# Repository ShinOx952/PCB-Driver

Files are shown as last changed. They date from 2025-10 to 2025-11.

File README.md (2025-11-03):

# Diseño de Driver de Potencia (Altium Designer) 

**Estado del Proyecto:** Diseño completado. El informe técnico completo está finalizado y disponible en este repositorio.

---

## 1. Vistas del Proyecto (Renders 3D)

**(Imagen 12: Vista Superior 3D)** 
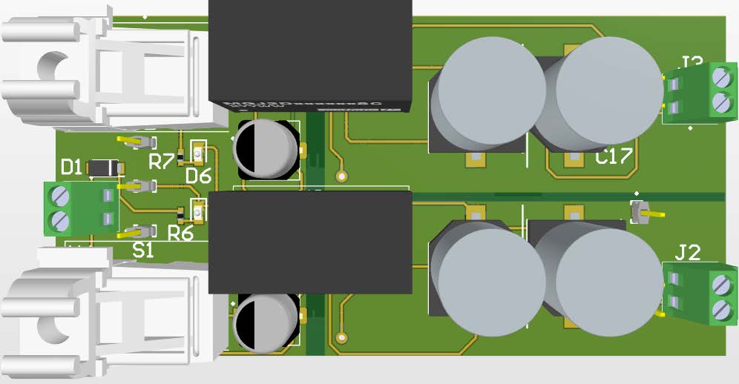
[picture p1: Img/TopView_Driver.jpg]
Vista Superior del PCB


**(Imagen 13: Vista Inferior 3D)** 
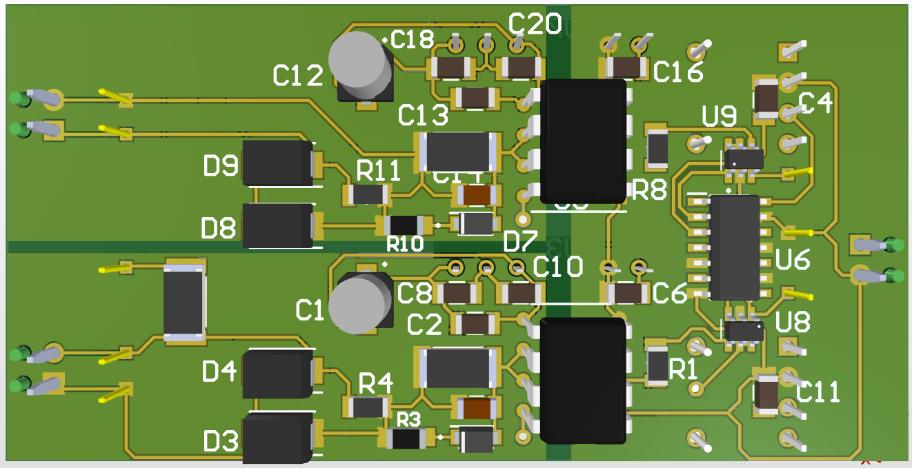
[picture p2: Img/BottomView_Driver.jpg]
Vista Inferior del PCB


---

## 2. Resumen del Proyecto

Este repositorio contiene todos los archivos de diseño y la documentación técnica del rediseño y optimización de un **driver de potencia**. El proyecto fue desarrollado íntegramente en **Altium Designer** con el objetivo de mejorar la funcionalidad, seguridad y eficiencia de un diseño base, enfocado en aplicaciones de alta fiabilidad como las energías renovables.

Las mejoras clave incluyen la **integración de compuertas lógicas** para la protección de la etapa de control y una optimización robusta del layout para manejar altas corrientes y minimizar interferencias (EMI).

### ➡️ Informe Técnico Completo
Para un análisis detallado de la metodología, los cálculos de la norma IPC, la lista de materiales (BOM) y la discusión técnica, consulte el informe completo:

**[Ver Informe Técnico (PDF)](./JARH_Proyecto_Final.pdf)**

---

## 3. Herramientas y Metodología

* **Software Principal:** Altium Designer
* **Actividades Clave:**
    * Creación de Bibliotecas Personalizadas (Símbolos, Footprints y Modelos 3D).
    * Diseño de Esquemático y Layout de PCB (2 Capas).
    * Generación de Archivos de Fabricación.

---

## 4. Características Técnicas Destacadas

* **Diseño para Alta Corriente (IPC-2221):** Cálculo y aplicación de anchos de pista específicos para manejar hasta **9A**, basados en la norma IPC-2221 para pistas externas.
* **Integridad de Señal y Aislamiento:** Implementación de **planos de tierra (GND) sólidos** y ruteo estratégico para mantener el aislamiento galvánico.
* **Diseño para Fabricación (DFM):** Verificación del diseño contra las capacidades del fabricante y uso de reglas de diseño (DRC) para validación.

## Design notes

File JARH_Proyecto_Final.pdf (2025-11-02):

Alumno:
José Ángel Rostro Hernández

### Asesor:

Gerardo Vázquez Guzmán

08 de Septiembre de 2025, San Luis Potosí, S.L.P., México

DISEÑO DE DRIVER

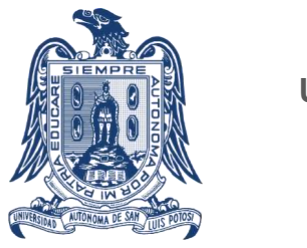
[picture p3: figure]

SEMICONDUCTOR DE POTENCIA

Universidad Autónoma de San Luis Potosí

Facultad de Ciencias

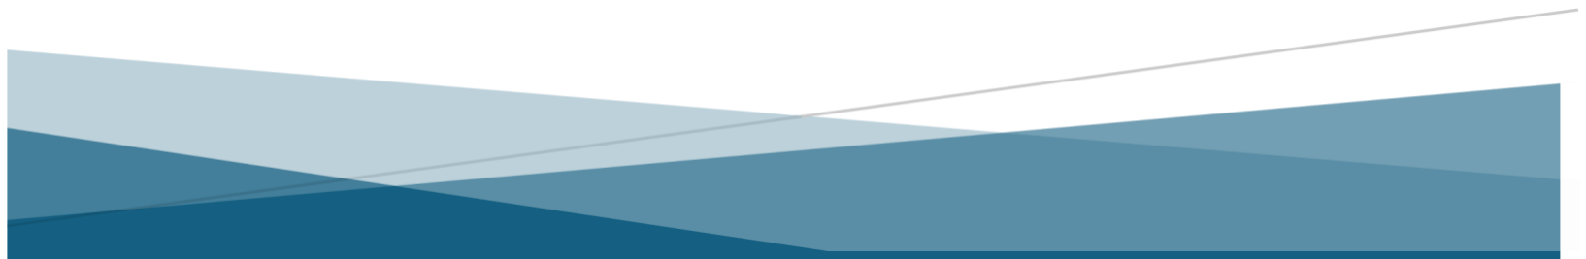
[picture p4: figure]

INTRODUCCIÓN

El diseño de drivers semiconductores de potencia para aplicaciones académicas y de prototipado requiere un enfoque especializado que considere tanto los aspectos teóricos como las particularidades prácticas de implementación. Este proyecto se centró en desarrollar un driver de potencia utilizando Altium Designer, haciendo énfasis en las técnicas avanzadas de diseño de PCB aplicadas específicamente a sistemas de potencia.

El reto principal consistió en integrar múltiples requerimientos técnicos: manejo de altas corrientes transitorias, aislamiento galvánico efectivo, generación de señales de +15V y -5V, y optimización del layout para minimizar interferencias electromagnéticas. Todo esto mientras se seguían las mejores prácticas de diseño y se seleccionaban componentes basados en un análisis riguroso de sus hojas técnicas. Durante el tiempo de trabajo se siguieron los siguientes lineamientos:

- Metodología de diseño integral: Desde la creación de bibliotecas personalizadas (símbolos, footprints y modelos 3D) hasta la implementación de reglas específicas para sistemas de potencia.
- Enfoque educativo: Documentación detallada de cada etapa del proceso, sirviendo como referencia para proyectos similares.
- Optimización técnica: Balance entre desempeño eléctrico, confiabilidad y factibilidad de fabricación.

Este trabajo demuestra cómo los principios de ingeniería pueden aplicarse sistemáticamente para desarrollar soluciones electrónicas complejas, particularmente en el ámbito de las energías renovables donde la eficiencia y robustez son críticas. La metodología empleada puede adaptarse a otros proyectos que requieran el diseño de circuitos de potencia con altos estándares de calidad.

OBJETIVOS

Este proyecto se enfocó en el rediseño y optimización de un driver semiconductor de potencia preexistente, con el propósito de mejorar su funcionalidad, seguridad y eficiencia. A partir de un esquemático y prototipo inicial, se implementaron modificaciones clave, como la incorporación de compuertas lógicas para protección, mientras se mantenía la compatibilidad con dispositivos IGBT y MOSFET.

Objetivos Técnicos

- Rediseño del esquemático

Partir del diseño base existente para implementar mejoras en la etapa de control y protección. Integrando compuertas lógicas que permitan un manejo más seguro de las señales de entrada, evitando estados indeterminados en la conmutación.

- Optimización del PCB en Altium Designer

Aplicar técnicas avanzadas de diseño para garantizar un ruteo eficiente, minimizando interferencias electromagnéticas (EMI).

- Validación mediante simulación y prototipado

Fabricar un prototipo funcional que permita evaluar su desempeño en un entorno real.

METODOLOGÍA

El diseño de un PCB en Altium Designer sigue un flujo estructurado que abarca desde la captura esquemática hasta la generación de archivos para fabricación. A continuación, se detalla cada etapa, su propósito y su relevancia en el desarrollo del driver de potencia.

### 1. Diseño del Esquemático

Define la estructura eléctrica del circuito, interconectando componentes según su funcionalidad.
a) Creación de Bibliotecas Personalizadas: Antes de dibujar el esquemático, es necesario contar con los símbolos y footprints de los componentes.
- Símbolos esquemáticos: Representación gráfica del componente (ej. resistencias, ICs, conectores).
- Footprints: Define el patrón físico de soldadura en el PCB (tamaño, pads, máscara de soldadura).
- Modelos 3D: Permite visualizar el PCB en un entorno realista y detectar interferencias mecánicas.

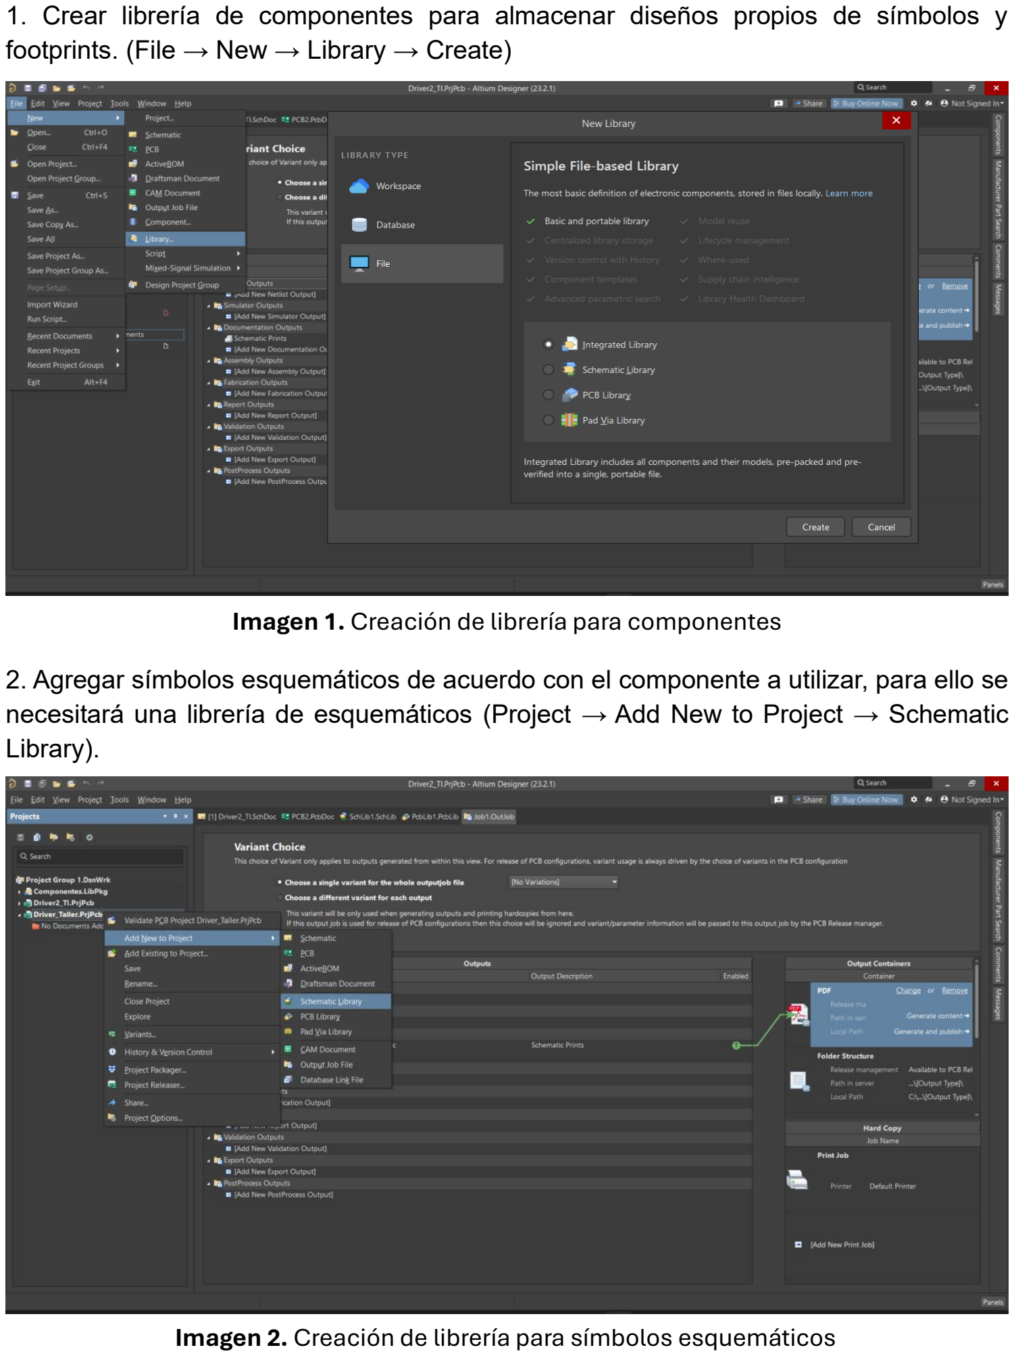
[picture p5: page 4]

1. Crear librería de componentes para almacenar diseños propios de símbolos y footprints. (File → New → Library → Create)
2. Agregar símbolos esquemáticos de acuerdo con el componente a utilizar, para ello se necesitará una librería de esquemáticos (Project → Add New to Project → Schematic Library).

### Imagen 1. Creación de librería para componentes

### Imagen 2. Creación de librería para símbolos esquemáticos

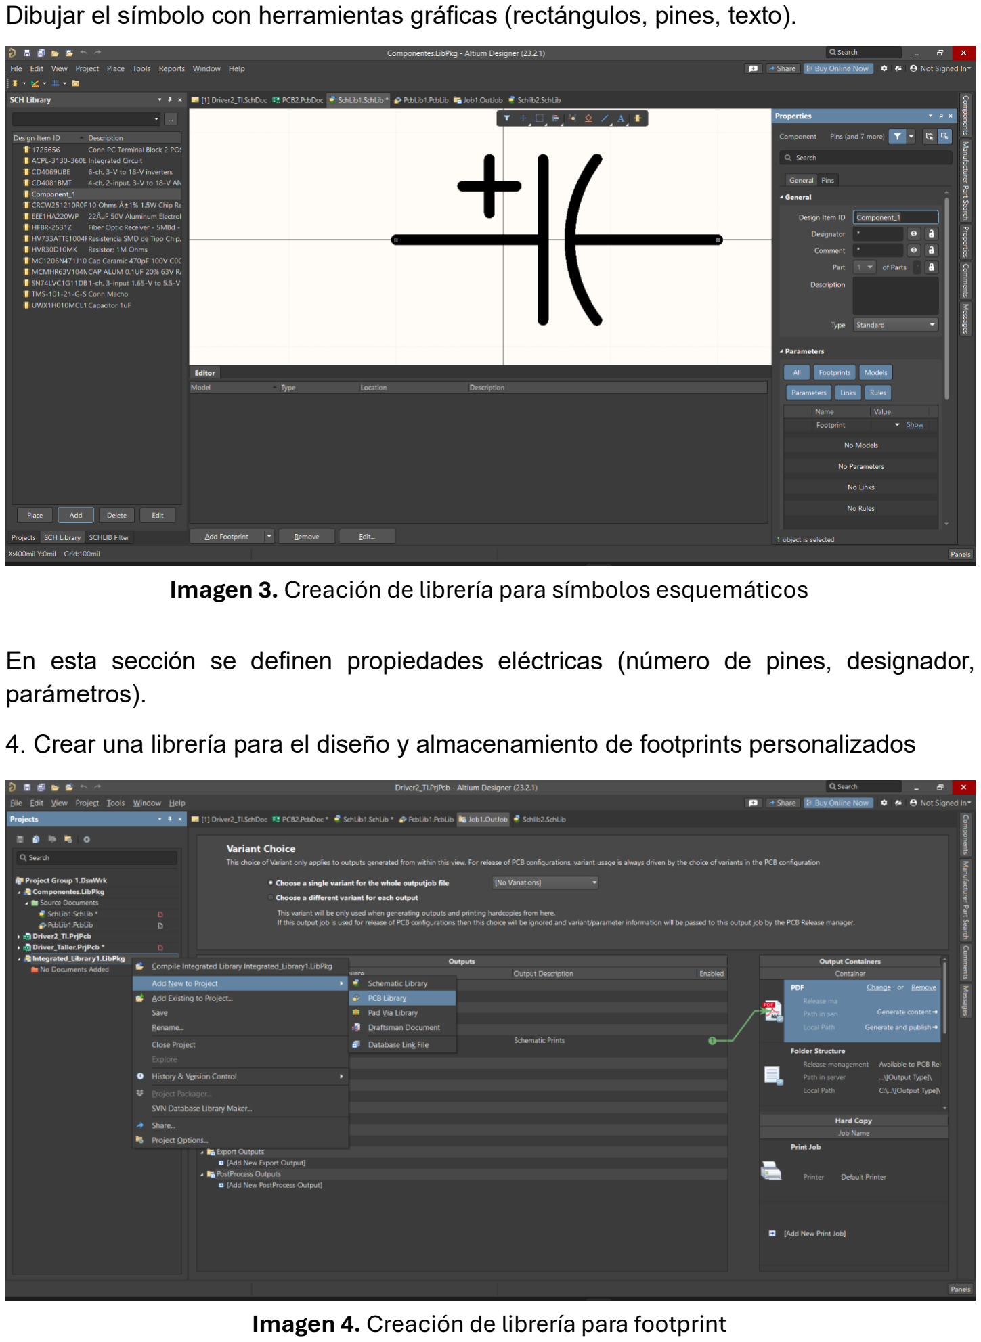
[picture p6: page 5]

Dibujar el símbolo con herramientas gráficas (rectángulos, pines, texto).

En esta sección se definen propiedades eléctricas (número de pines, designador, parámetros).

4. Crear una librería para el diseño y almacenamiento de footprints personalizados

### Imagen 3. Creación de librería para símbolos esquemáticos

### Imagen 4. Creación de librería para footprint

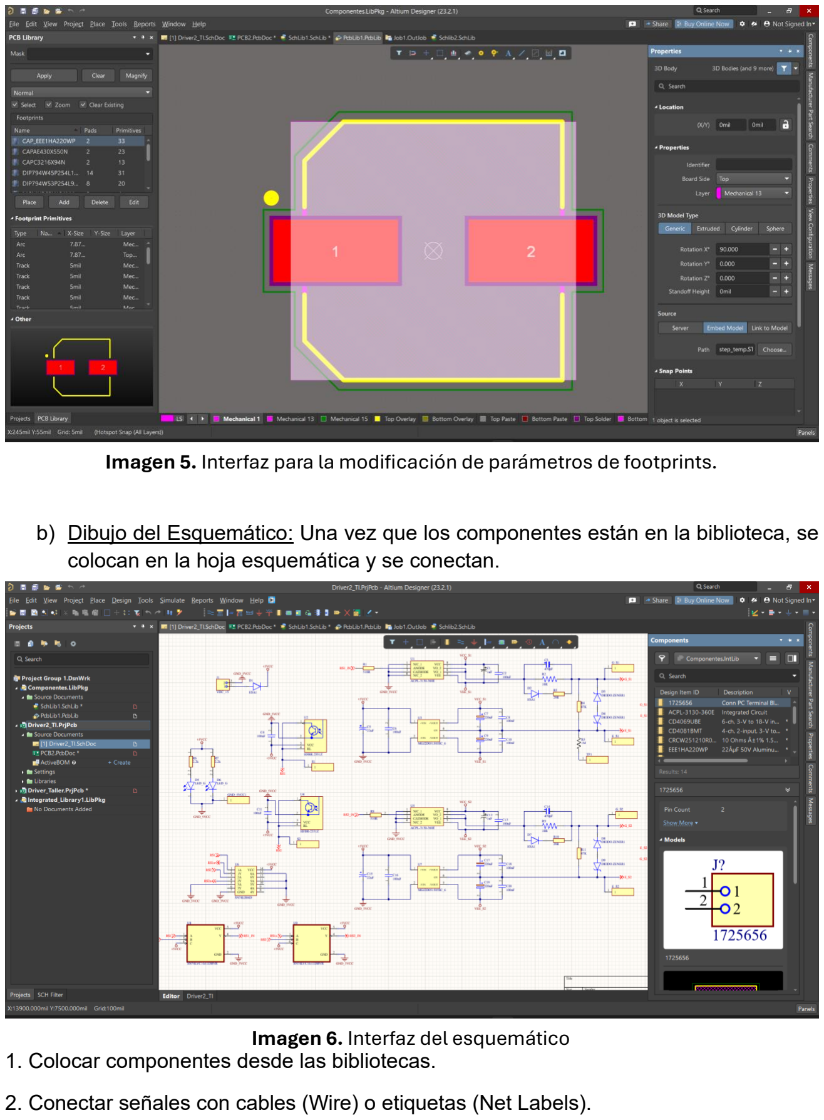
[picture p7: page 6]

**Ejemplo aplicado al proyecto**:

- Se diseñó el símbolo del **optoacoplador ACPL-3130** basado en su datasheet, asignándole un footprint SOIC-6.
- Se verificó que el modelo 3D coincidiera con las dimensiones reales para evitar conflictos en el ensamblado.
b) Dibujo del Esquemático: Una vez que los componentes están en la biblioteca, se colocan en la hoja esquemática y se conectan.
1. Colocar componentes desde las bibliotecas.
2. Conectar señales con cables (Wire) o etiquetas (Net Labels).

Imagen 5. Interfaz para la modificación de parámetros de footprints.

### Imagen 6. Interfaz del esquemático

3. Anotar automáticamente (Tools → Annotate) para asignar referencias únicas (R1, C2, U3).
4. Verificar reglas eléctricas (ERC – Electrical Rule Check) para detectar pines flotantes o conexiones incorrectas.

El esquemático del driver incluyó tres secciones claras: entrada óptica, procesamiento con compuertas lógicas y salida de potencia.

### 2. Diseño del PCB (Layout)

Transforma el esquemático en un diseño físico optimizado para fabricación.
a) Configuración Inicial
1. Crear un nuevo PCB (File → New → PCB).
2. Definir tamaño de la placa y capas (en este caso, 2 capas: Top y Bottom).
3. Importar componentes desde el esquemático (Design → Update PCB).
b) Colocación de Componentes (Placement)
- Jerarquía de señales: Colocar primero componentes críticos (ej. optoacopladores cerca del borde para aislamiento).
- Flujo de señal: Ordenar etapas (entrada → procesamiento → salida) para minimizar cruce de pistas.
- Disipación térmica: Dejar espacio alrededor de componentes que generan calor.

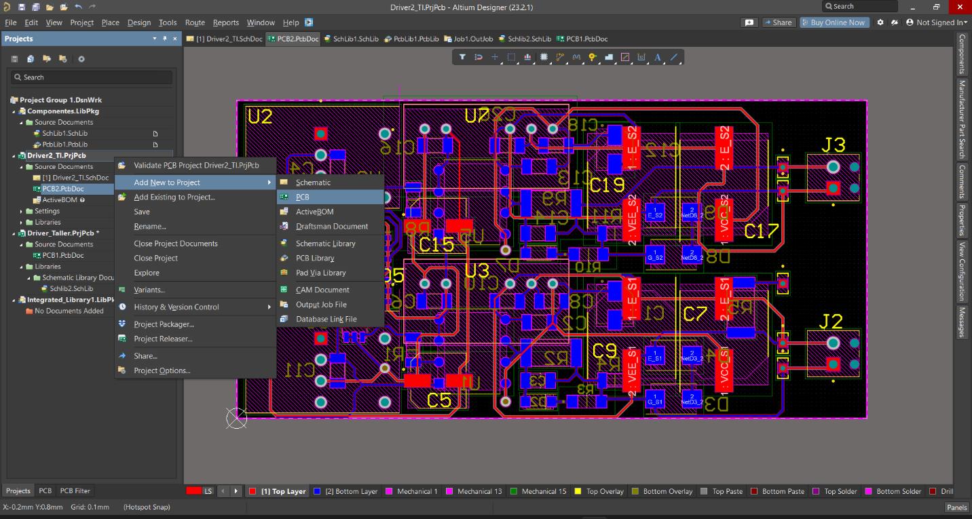
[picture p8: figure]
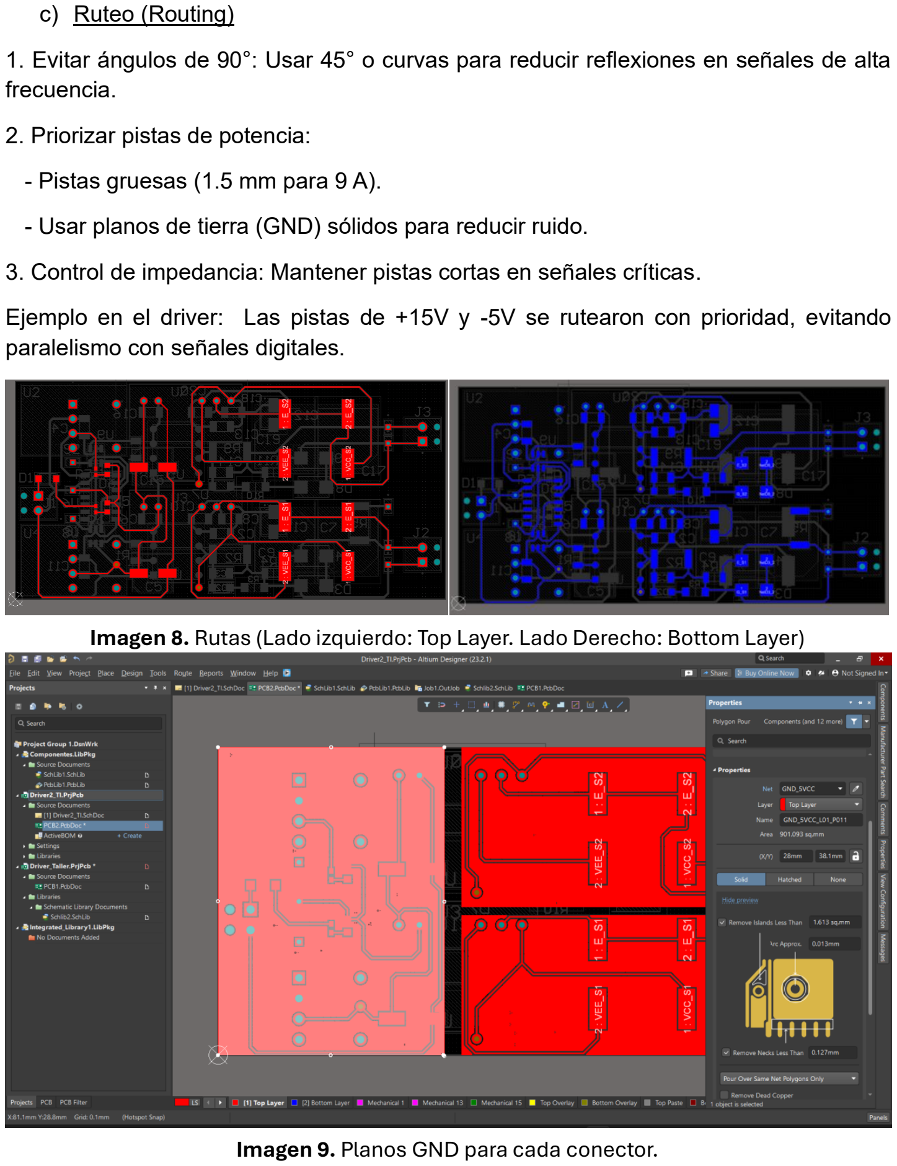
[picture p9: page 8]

c) Ruteo (Routing)
1. Evitar ángulos de 90°: Usar 45° o curvas para reducir reflexiones en señales de alta frecuencia.
2. Priorizar pistas de potencia:
- Pistas gruesas (1.5 mm para 9 A).
- Usar planos de tierra (GND) sólidos para reducir ruido.
3. Control de impedancia: Mantener pistas cortas en señales críticas.

Ejemplo en el driver: Las pistas de +15V y -5V se rutearon con prioridad, evitando paralelismo con señales digitales.

### Imagen 8. Rutas (Lado izquierdo: Top Layer. Lado Derecho: Bottom Layer)

Imagen 9. Planos GND para cada conector.

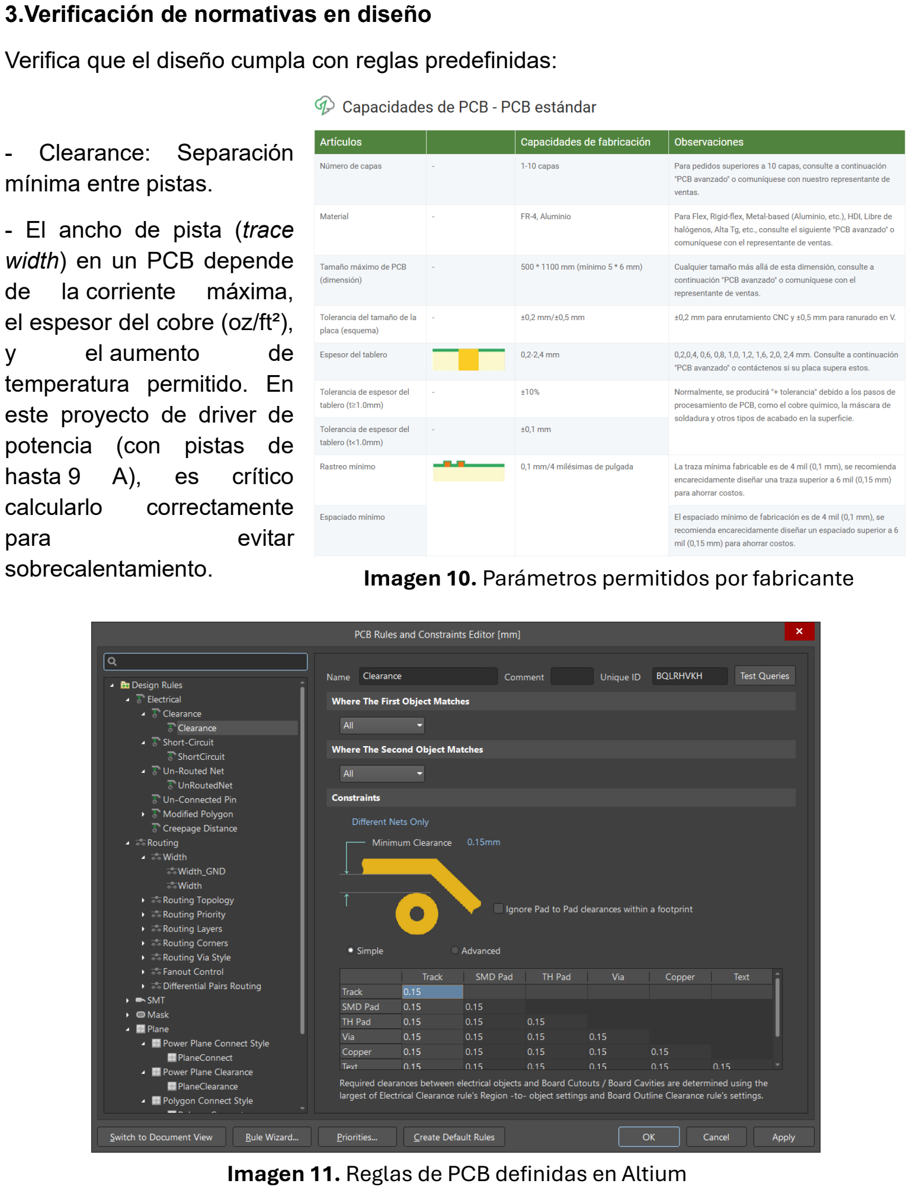
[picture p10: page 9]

3.Verificación de normativas en diseño

Verifica que el diseño cumpla con reglas predefinidas:

- | Clearance: | Separación
mínima entre pistas.
- El ancho de pista (trace width) en un PCB depende
de | la corriente | máxima,
el espesor del cobre (oz/ft²),
y | el aumento | de
temperatura permitido. En
este proyecto de driver de potencia (con pistas de
hasta 9 | A), | es | crítico
calcularlo | correctamente
para | | | evitar
sobrecalentamiento.

### Imagen 10. Parámetros permitidos por fabricante

### Imagen 11. Reglas de PCB definidas en Altium

La | norma IPC-2221 proporciona | una | fórmula | para | pistas | externas | (capa
superior/inferior):

Ancℎo(mil) =

| | | I k(∆T | 0.44)

Donde:

I = Corriente máxima (A)

∆T = Aumento de temperatura permitido (°C)

k = Constante: 0.024 para pistas externas (Top/Bottom).

El cálculo asegura que las pistas no se sobrecalienten ni generen caídas de voltaje excesivas.

| • Pistas de Potencia
- Corriente máxima: 9 A.
- Espesor de cobre: 2 oz/ft² (70 µm, estándar).
- ΔT: 20°C (para balancear disipación y espacio).

Ancℎo(mil) =

| 9A (0.024 )(10⁰.44)
= 237mils = 6mm (En el caso de un espesor de 1 oz/ft²)

El cobre más grueso reduce el ancho necesario. El factor de corrección es:

Factor = (

| | | 1oz 2oz)
| | | 0.725
| | | | = 0.6

Ancho (2oz) = 237mils (0.6) = 142mils = 3.6mm

Este es el máximo ancho de pista que se debe tener para que circule el máximo de corriente, pero podemos hacer las pistas más delgadas dentro del diseño ya que no se trabajara con él la potencia máxima en un estado común.

- Pistas para Señales de Baja Corriente (≤20 mA)
- Corriente máxima: 20 mA.
- Espesor de cobre: 1 oz/ft² (35 µm, estándar).
- ΔT (aumento de temperatura permitido): 10°C (conservador para señales de
| control).
| Ancℎo(mil) = | 20mA
(0.024 )(10⁰.44)

= 1.2mils = 0.03mm

Debido a que el fabricante recomienda utilizar 0.2mm se utilizara dicha medida.

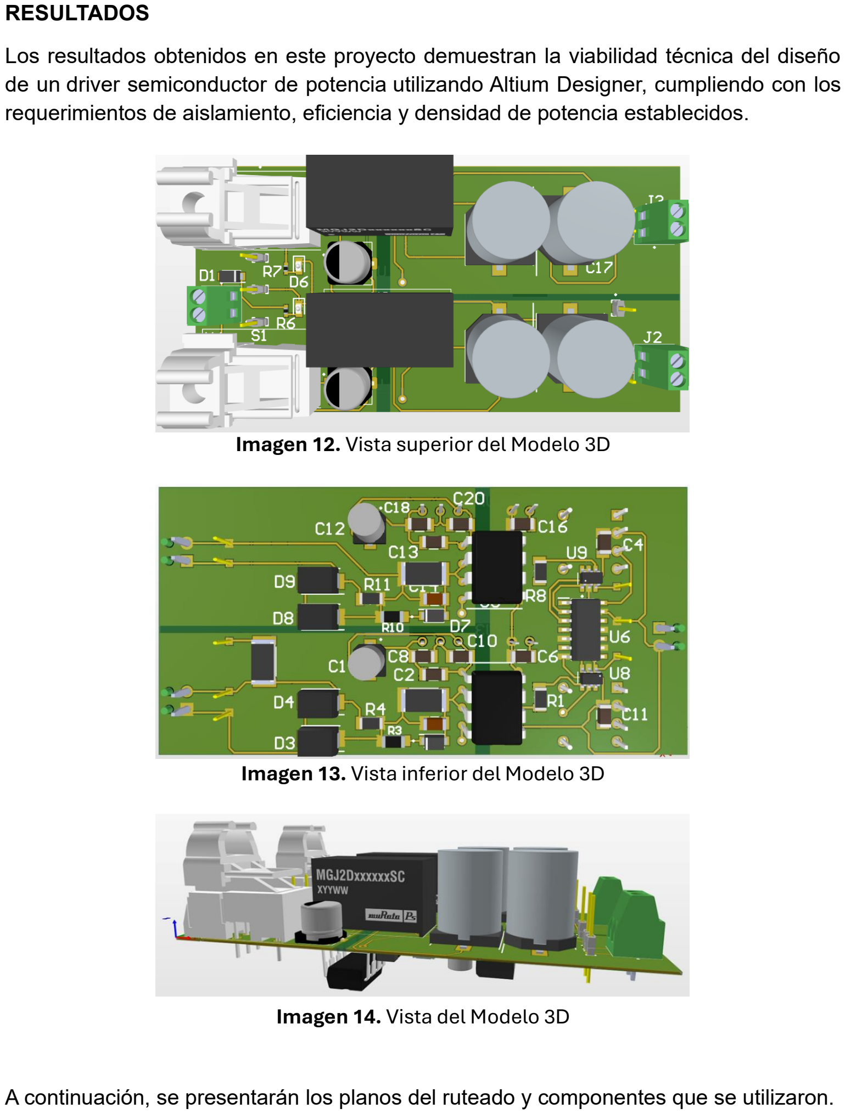
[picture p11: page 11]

RESULTADOS

Los resultados obtenidos en este proyecto demuestran la viabilidad técnica del diseño de un driver semiconductor de potencia utilizando Altium Designer, cumpliendo con los requerimientos de aislamiento, eficiencia y densidad de potencia establecidos.

A continuación, se presentarán los planos del ruteado y componentes que se utilizaron.

### Imagen 12. Vista superior del Modelo 3D

### Imagen 13. Vista inferior del Modelo 3D

### Imagen 14. Vista del Modelo 3D

No. Parte Newark | No. Parte Fabricante | Descripción
34C6819 | 12063C104MAT2A | Capacitor de 0.1uF SMD [1206]
90W2923 (http://mexico.newark.com/multicomp/mc1206n471j101ct/capacitor-mlcc-470pf-100v-np0/dp/90W2923) | MC1206N471J101CT (http://mexico.newark.com/multicomp/mc1206n471j101ct/capacitor-mlcc-470pf-100v-np0/dp/90W2923) | Capacitor Cerámico Multicapa SMT, 1206 [Métrica 3216], 470 pF, 100 V, ± 5%
58R3636 | UWX1H010MCL1GB | Capacitor Electrolítico de Aluminio SMT, Radial - SMD, 1 µF, 50 V
58R3636 | UWX1H010MCL1GB | Capacitor Electrolítico, 0.1 µF, 63 V, Serie MCMHR, ± 20%, Conexión Radial, 4 mm
53W3820 (http://mexico.newark.com/panasonic-electronic-components/eee-1ha220wp/aluminum-electrolytic-capacitor/dp/53W3820) | EEE-1HA220WP | Capacitor Electrolítico de Aluminio SMT, Radial - SMD, 22 µF, 50 V
94M5768 | MAL215097102E3 | Capacitor Electrolítico de Aluminio SMT, Radial - SMD, 220 µF, 50 V
58Y4429 | ACPL-3130-000E | Optoacoplador Driver de Compuerta 3750Vrms
84AH5907 | HV733ATTE1004F | Resistencia de pelicula delgada 1MOhms a 1W SMD [2512]
57K2482 | CRCW1206510RFKEA | Resistencia de pelicula delgada 510Ohms a 0.25W SMD [1206]
79M6132 | MC1206S4F100JT5E (http://mexico.newark.com/multicomp/mc1206s4f100jt5e/res-thick-film-10r-1-0-25w-1206/dp/79M6132) | Resistencia SMD Chip, Película Gruesa, 10 ohm, 200 V, 1206
53K2422 | CRCW120647K0FKEA | Resistencia de pelicula delgada 47KOhms a 0.25W SMD [1206]
90W3811 (http://mexico.newark.com/panasonic-electronic-components/erj-8enf30r0v/res-thick-film-30r-1-0-25w-1206/dp/90W3811) | ERJ-8ENF30R0V (http://mexico.newark.com/panasonic-electronic-components/erj-8enf30r0v/res-thick-film-30r-1-0-25w-1206/dp/90W3811) | Resistencia SMD Chip, Película Gruesa, 30 ohm, 200 V, 1206
71K0286 | HFBR-2531Z | Fibras_receptor_Rx_HFBR-2531
53X9031 | MGJ2D241505SC | Fuente de alimentacion 2W, 24V a 5V
45J2455 | 1SMB5931BT3G | Diodo Zener 3W, 18V
58K1379 | ES1A | Diodo de recuperacion rapida, 1A, 50V
72K9435 | SN74LS04D | 74LS04, 1 Entrada, 8 mA, 4.75 V a 5.25 V, SOIC-14
29AH7598 | SN74LVC1G11DBVR | 3-input 1.65-V to 5.5-V 32 mA drive strength AND gate
53K3941 | Resistencia SMD Chip, Película Gruesa, 10 ohm, 500 V, 2512 [6432 Metric], 1 W, ± 1%
18R3518 | Resistencia SMD Chip, Película Gruesa, 18 ohm, 200 V, 2512 [6432 Metric], 1 W, ± 5%
18R3531 | Resistencia SMD Chip, Película Gruesa, 22 ohm, 200 V, 2512 [6432 Metric], 1 W, ± 5%

LISTA DE COMPONENTES

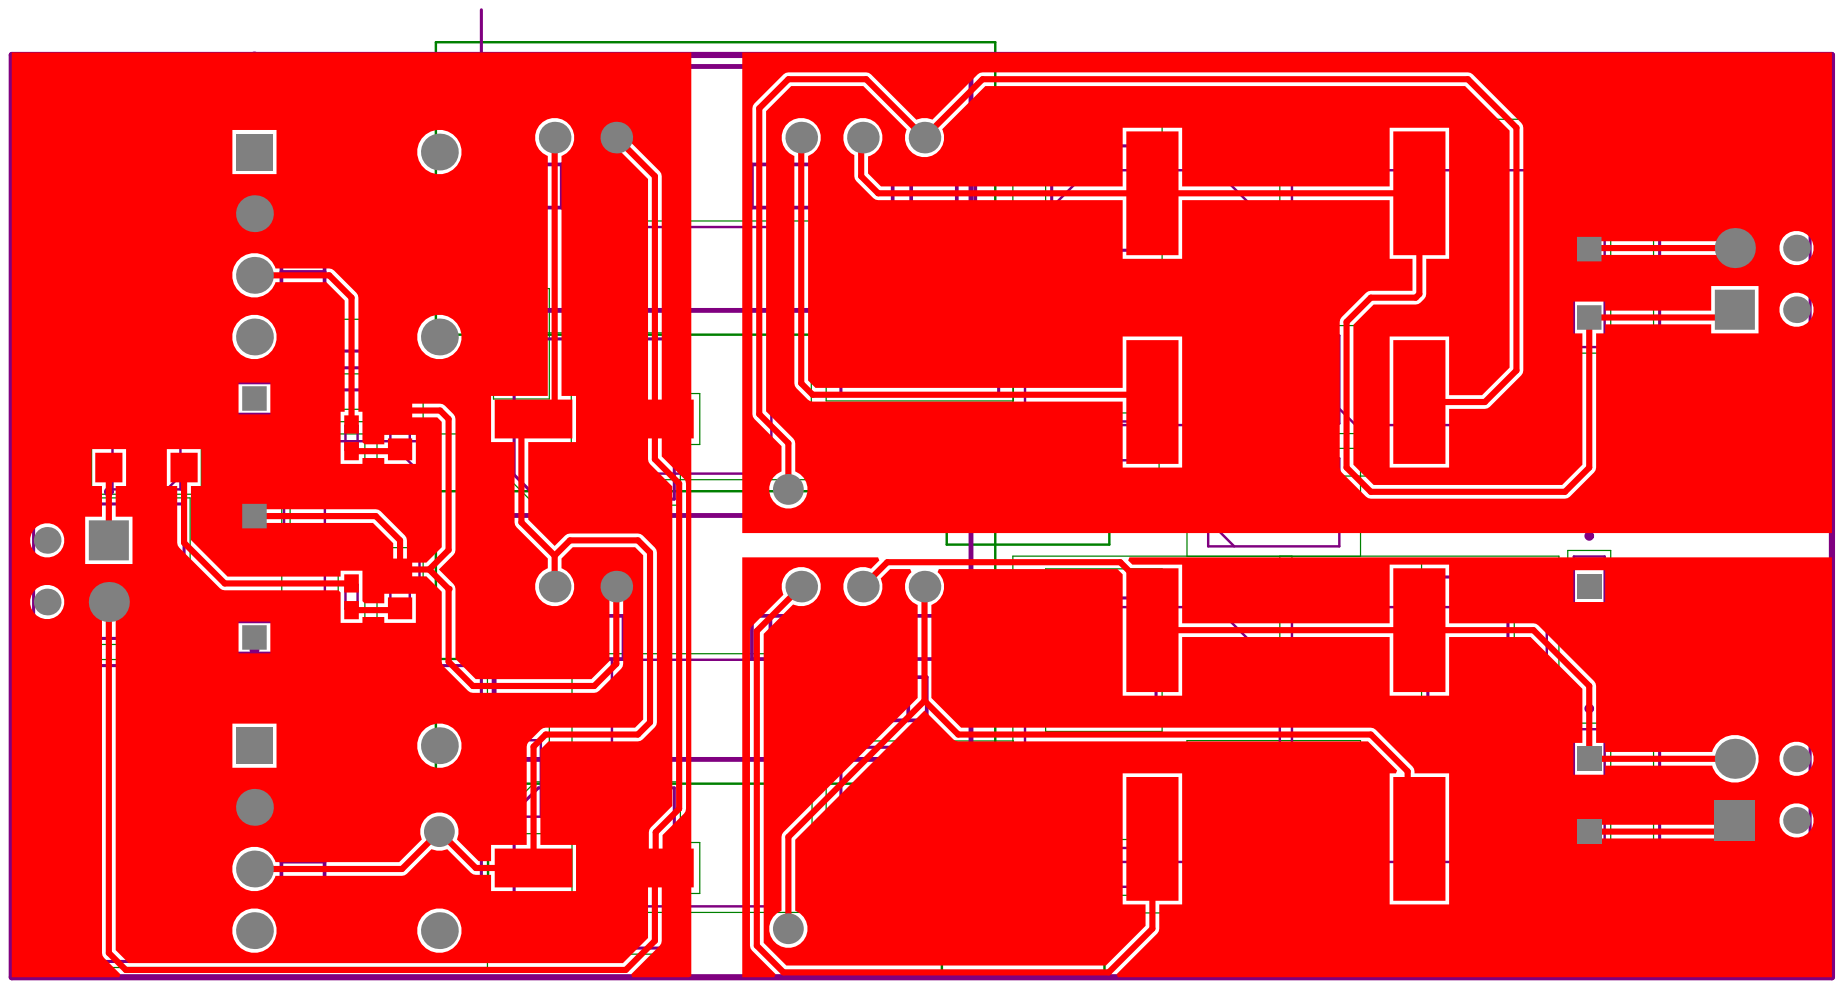
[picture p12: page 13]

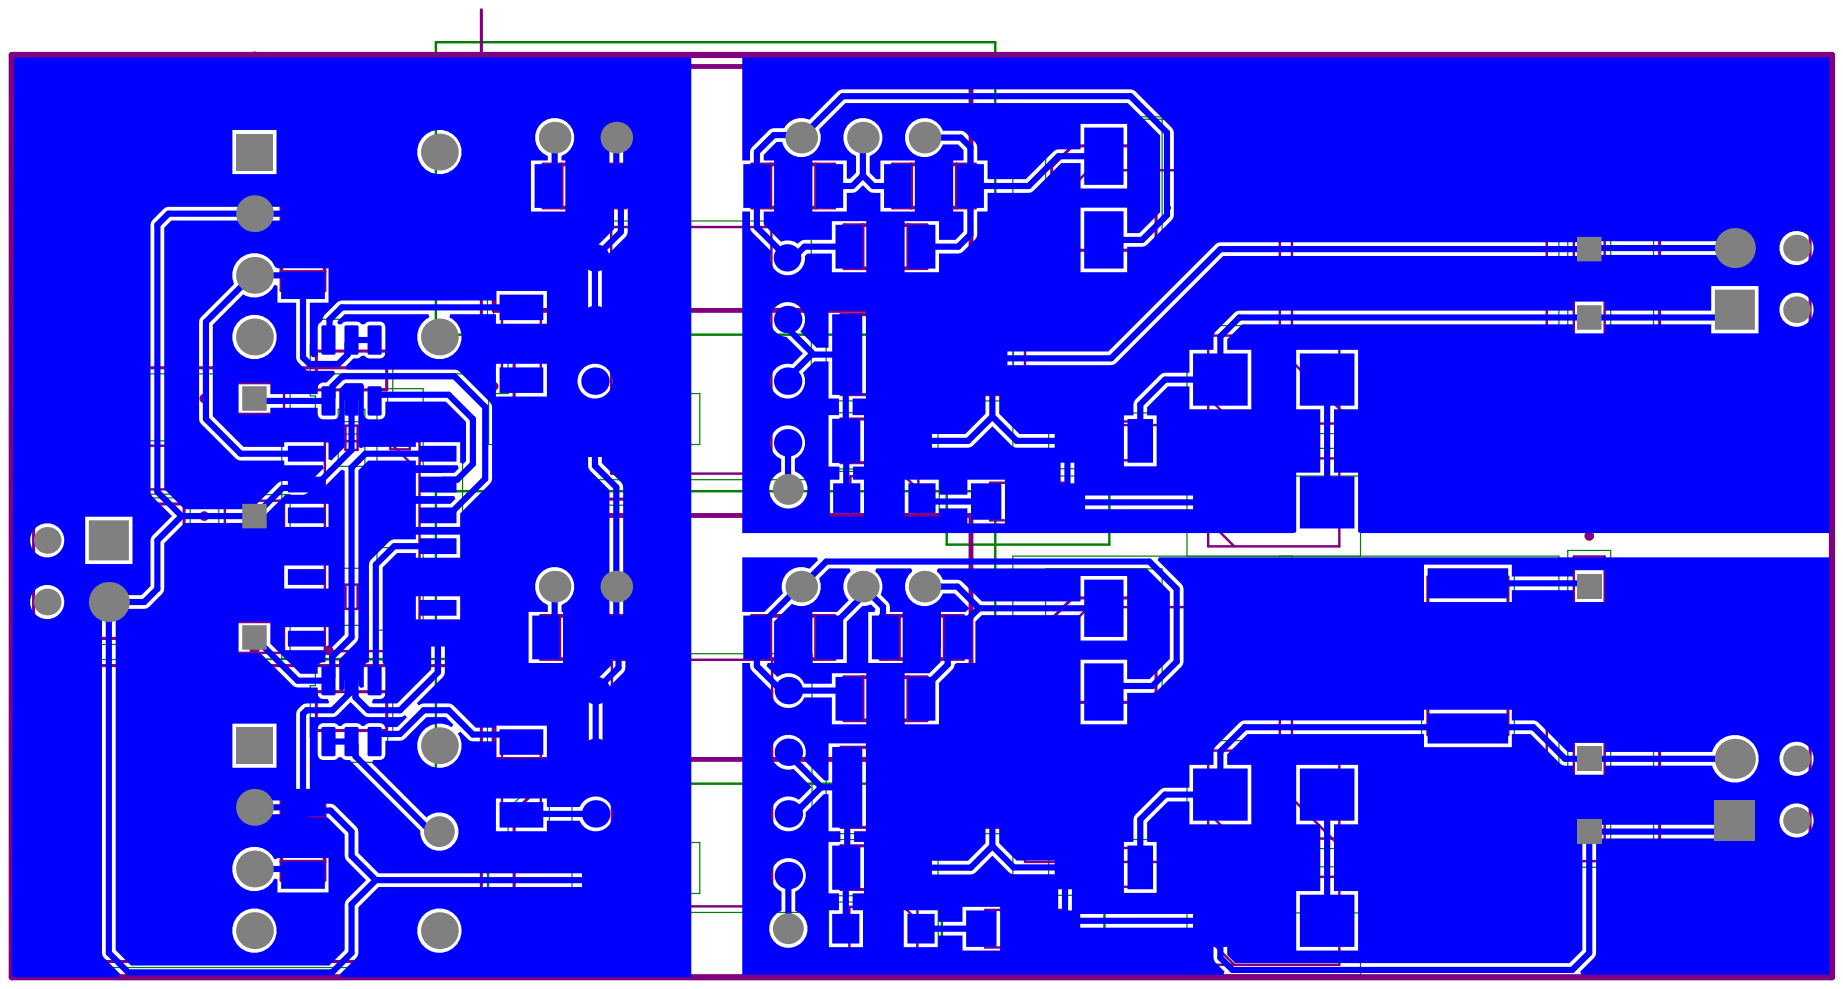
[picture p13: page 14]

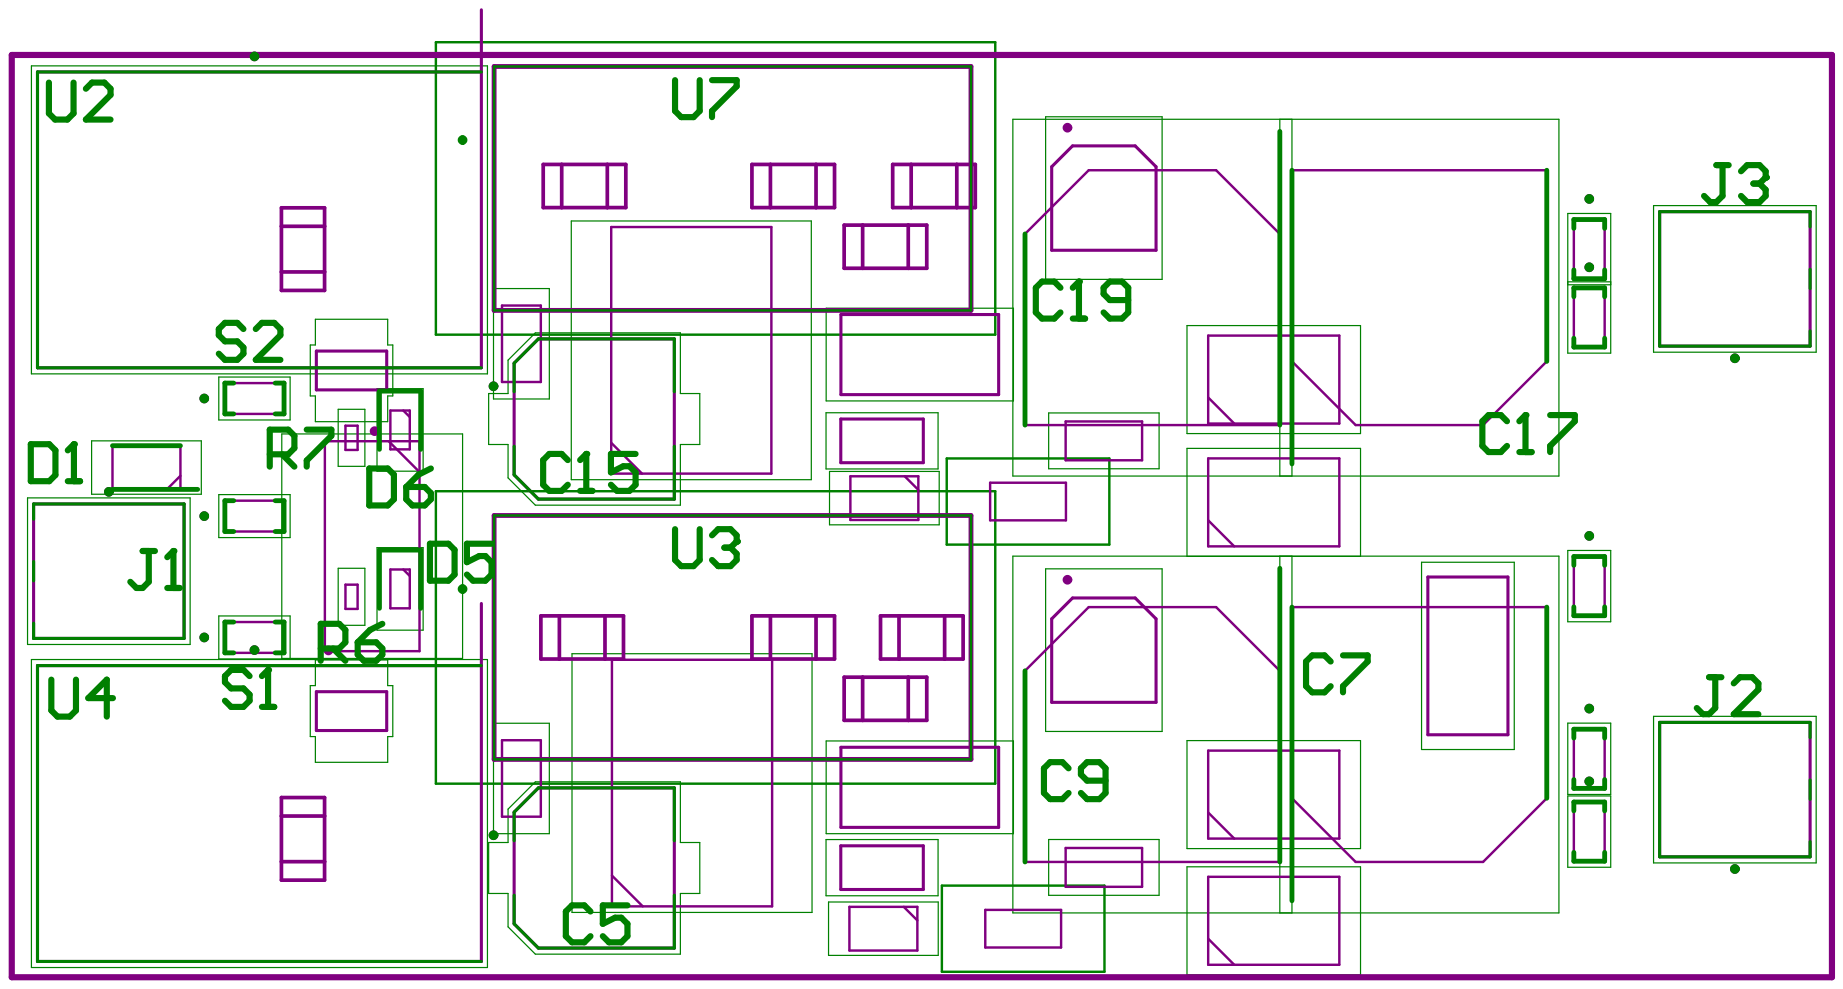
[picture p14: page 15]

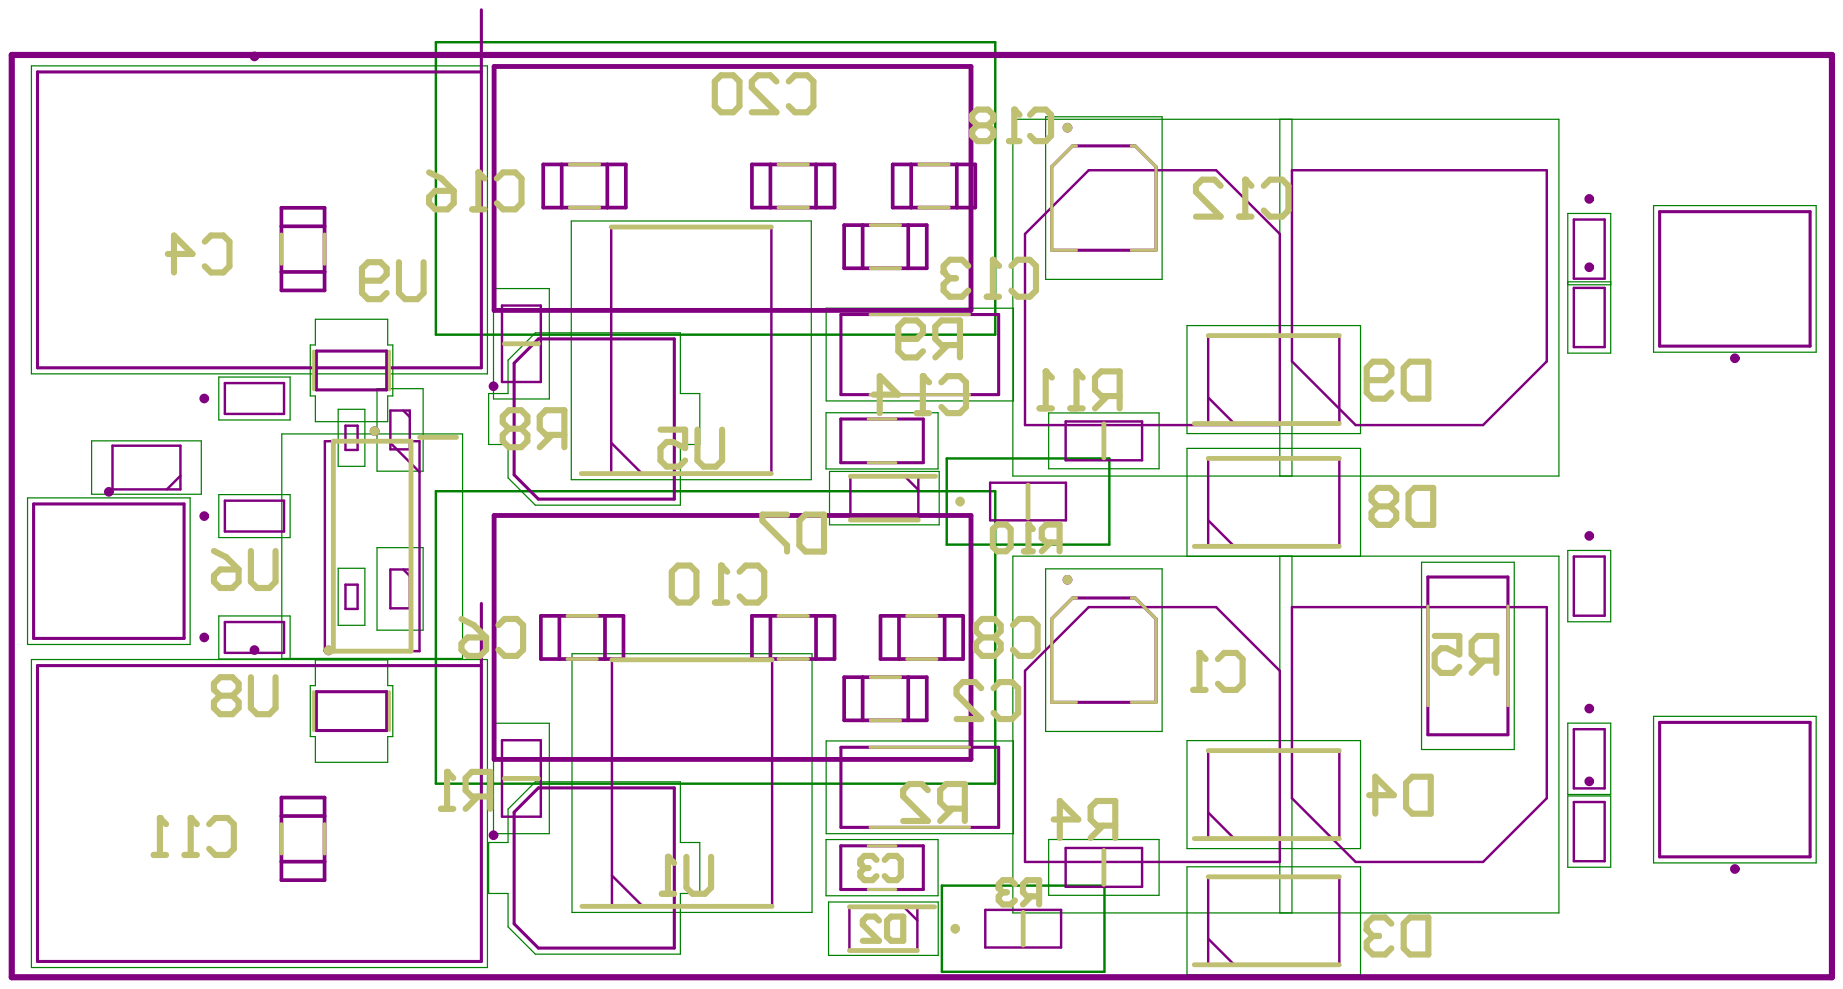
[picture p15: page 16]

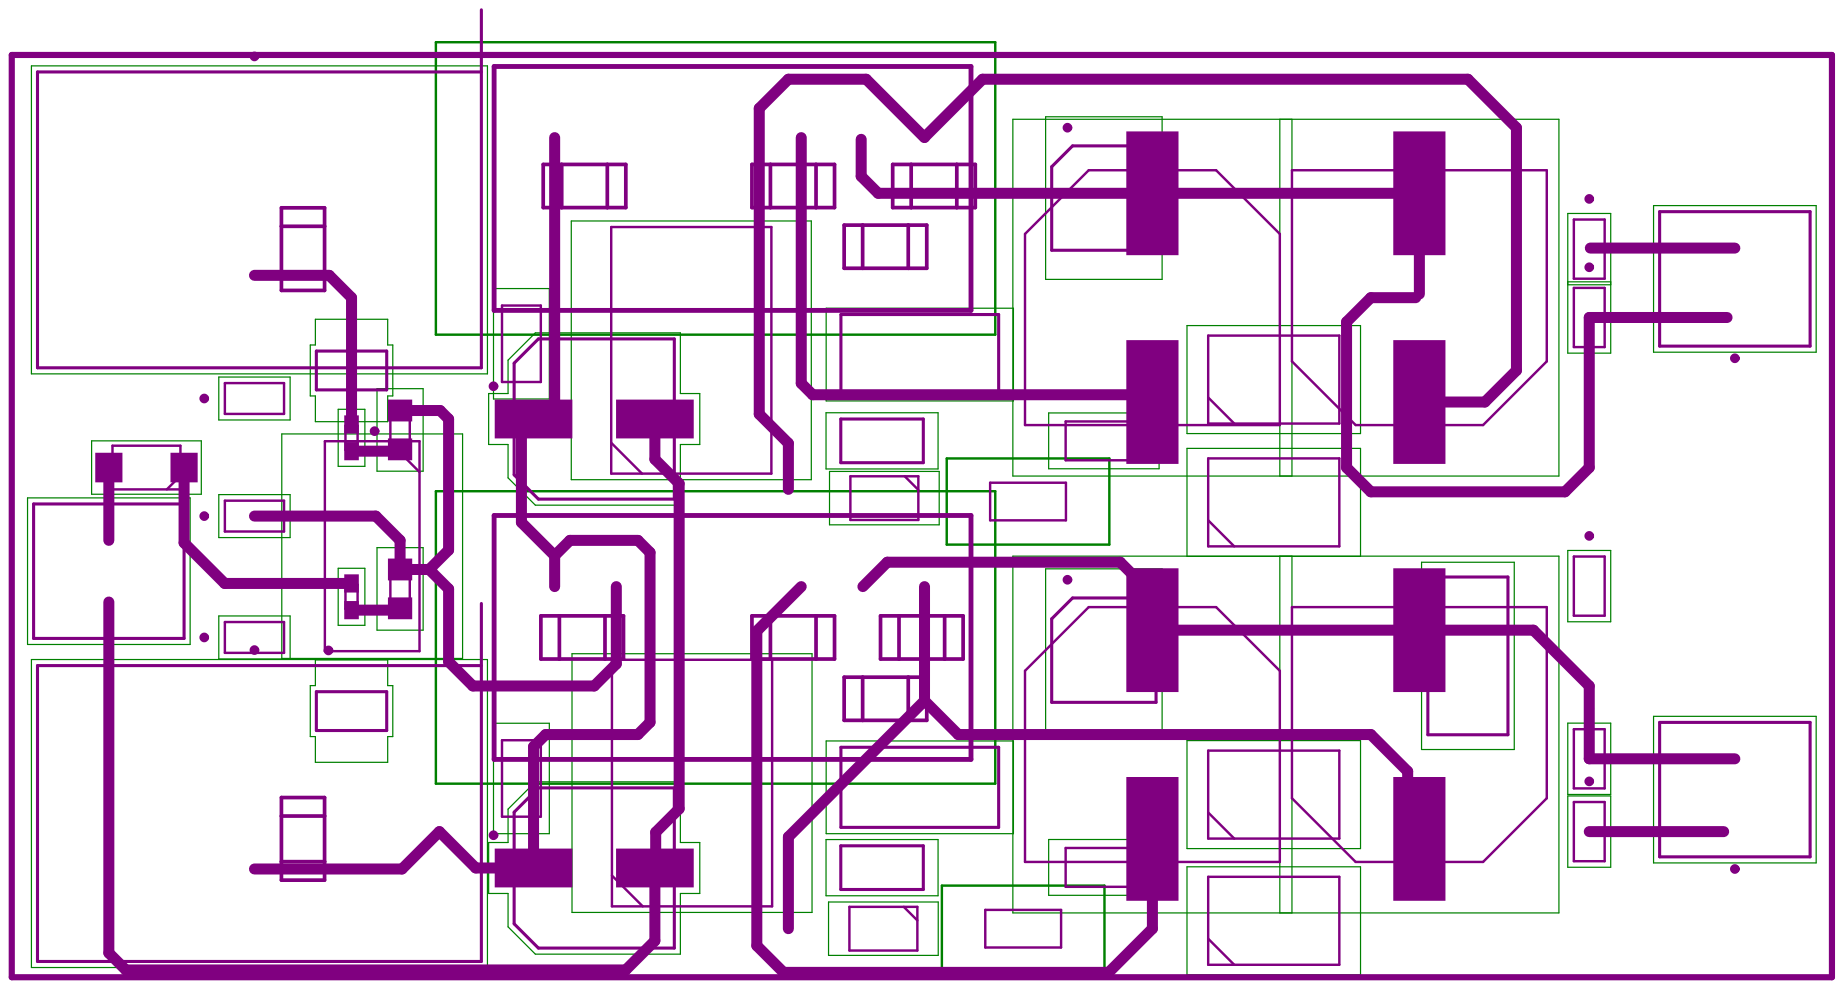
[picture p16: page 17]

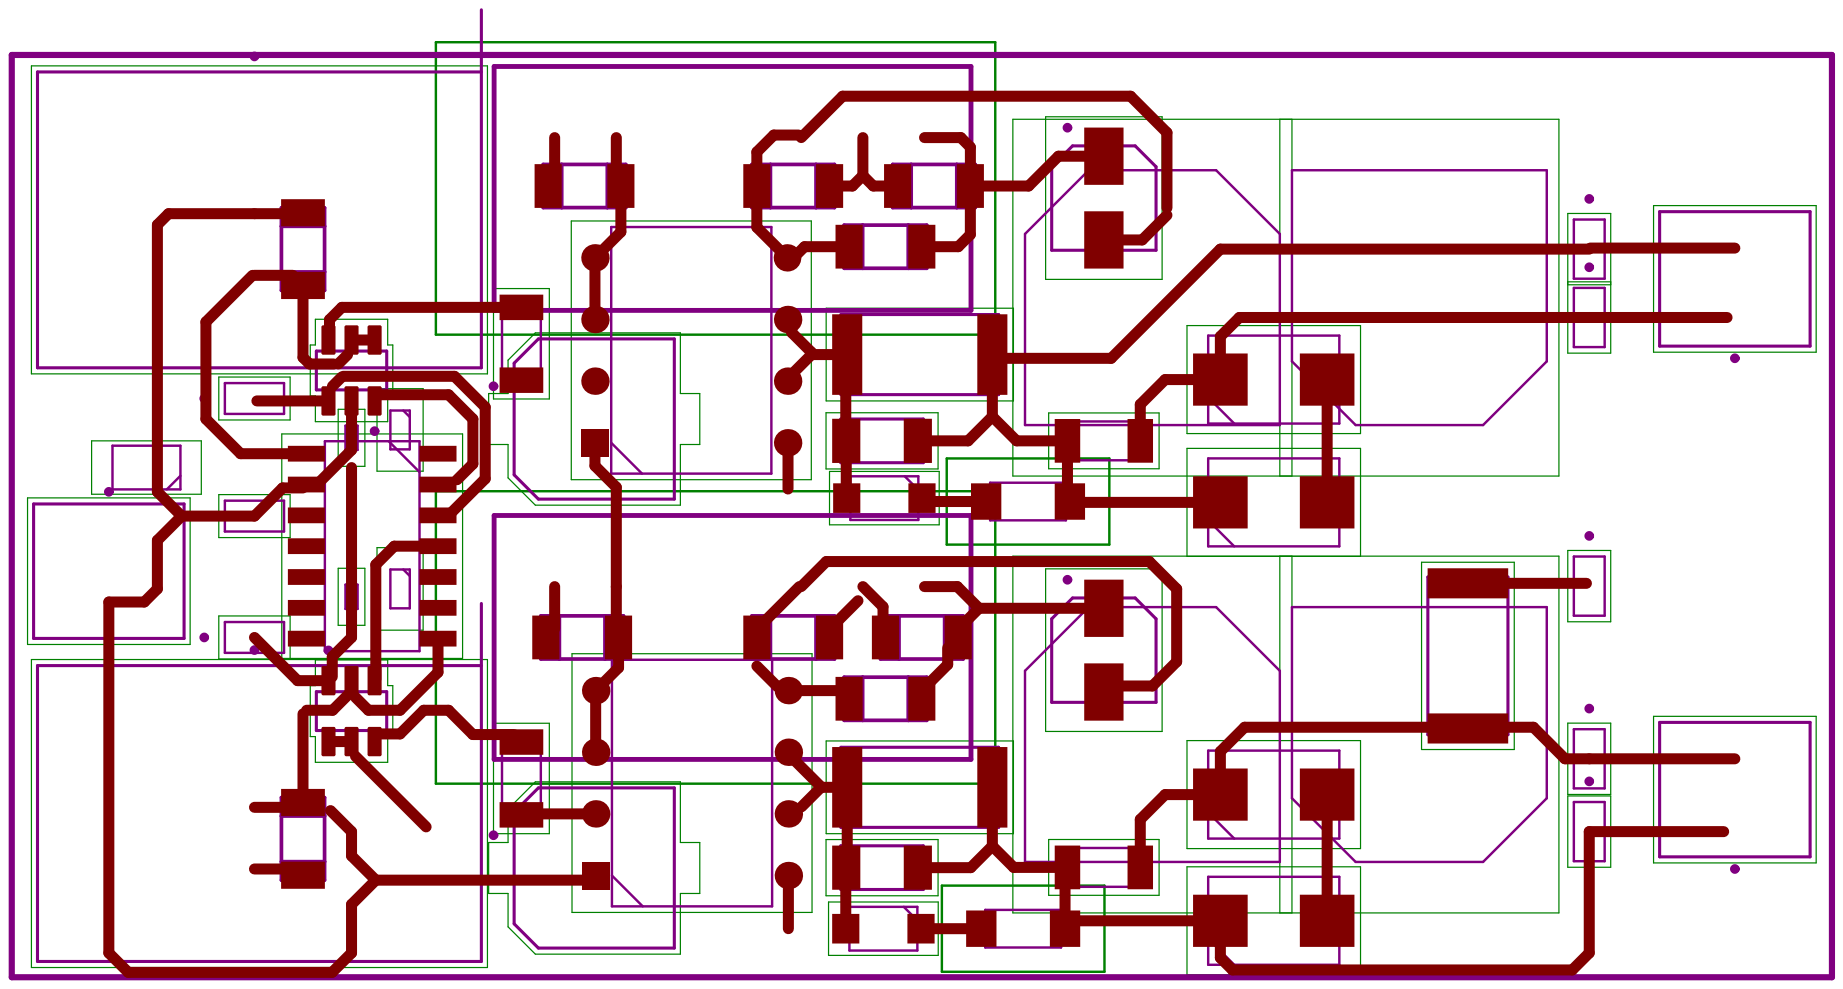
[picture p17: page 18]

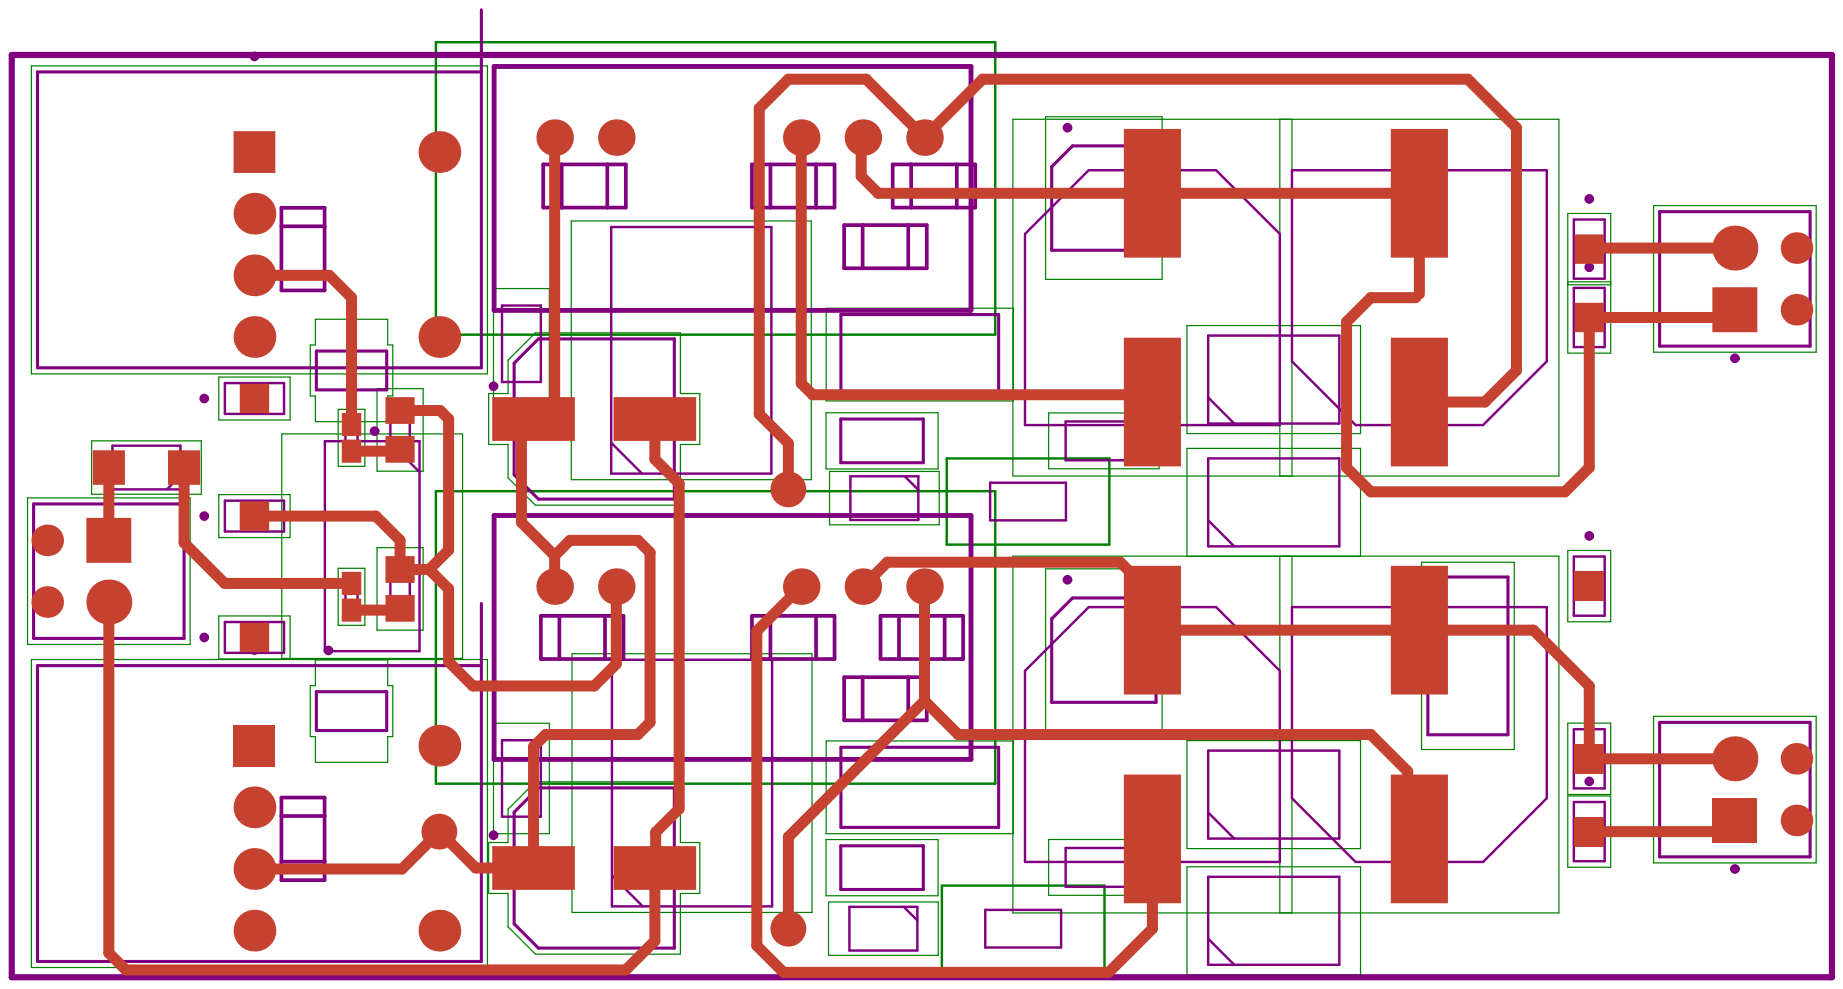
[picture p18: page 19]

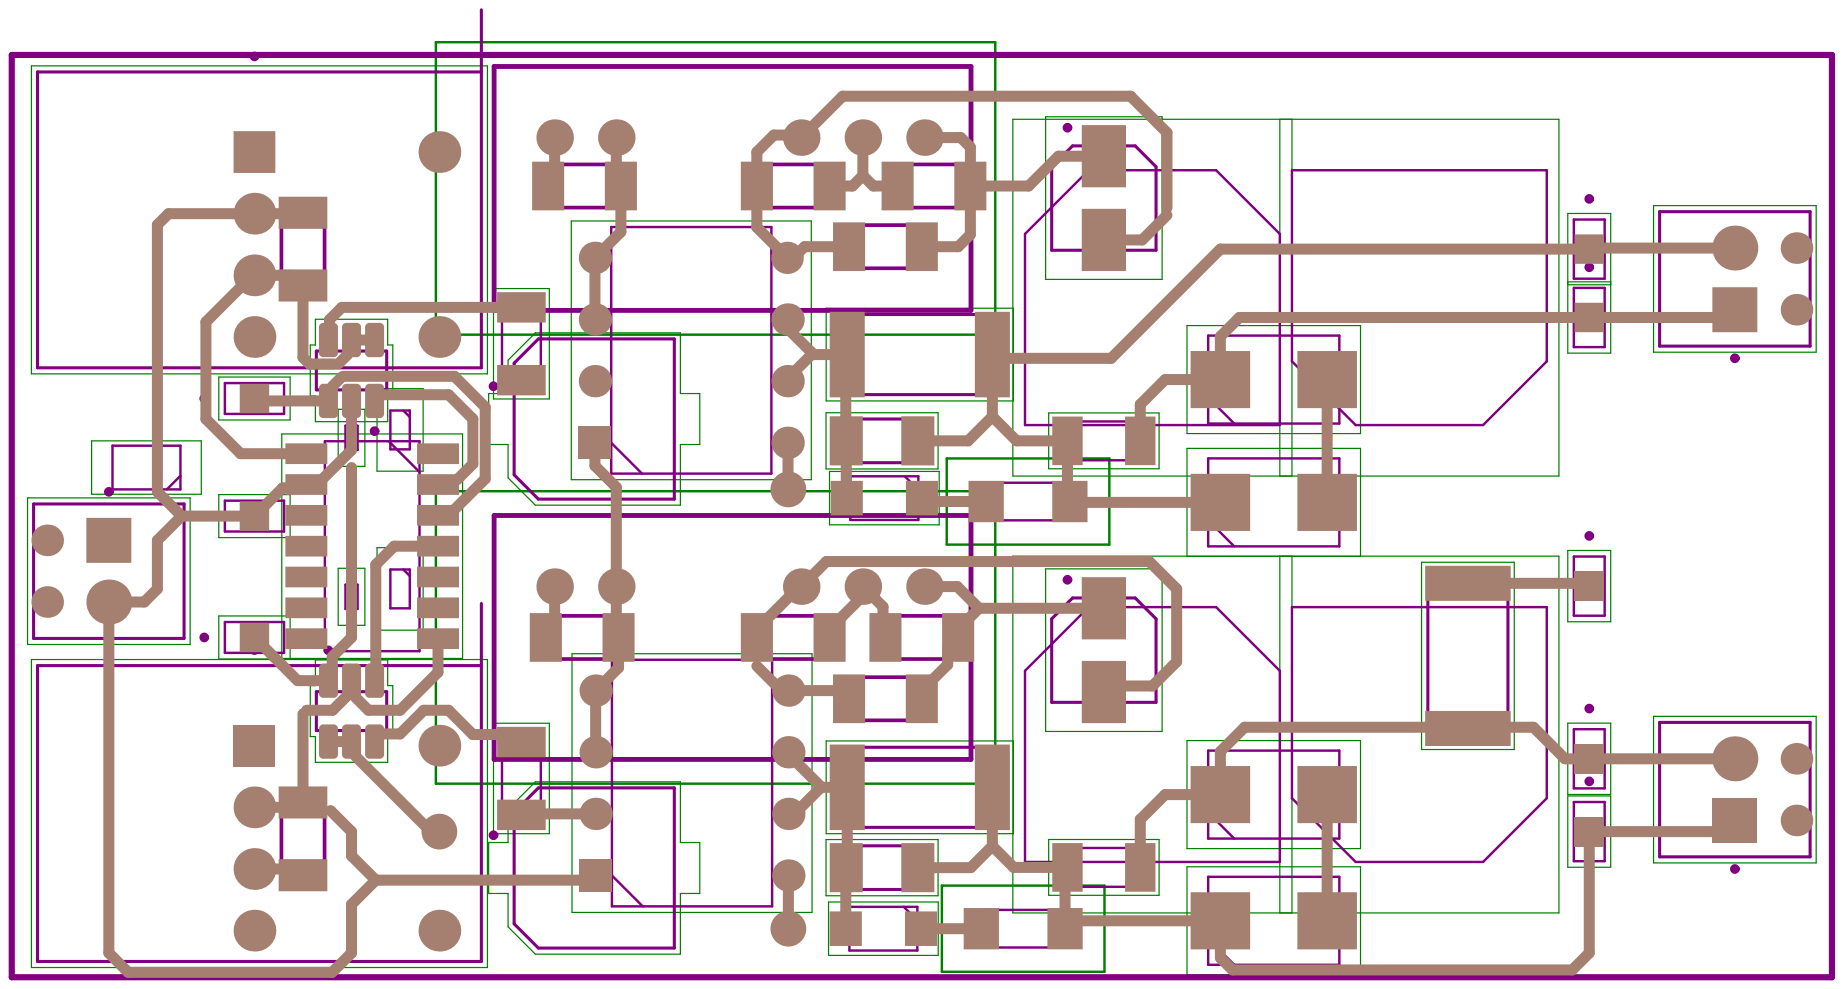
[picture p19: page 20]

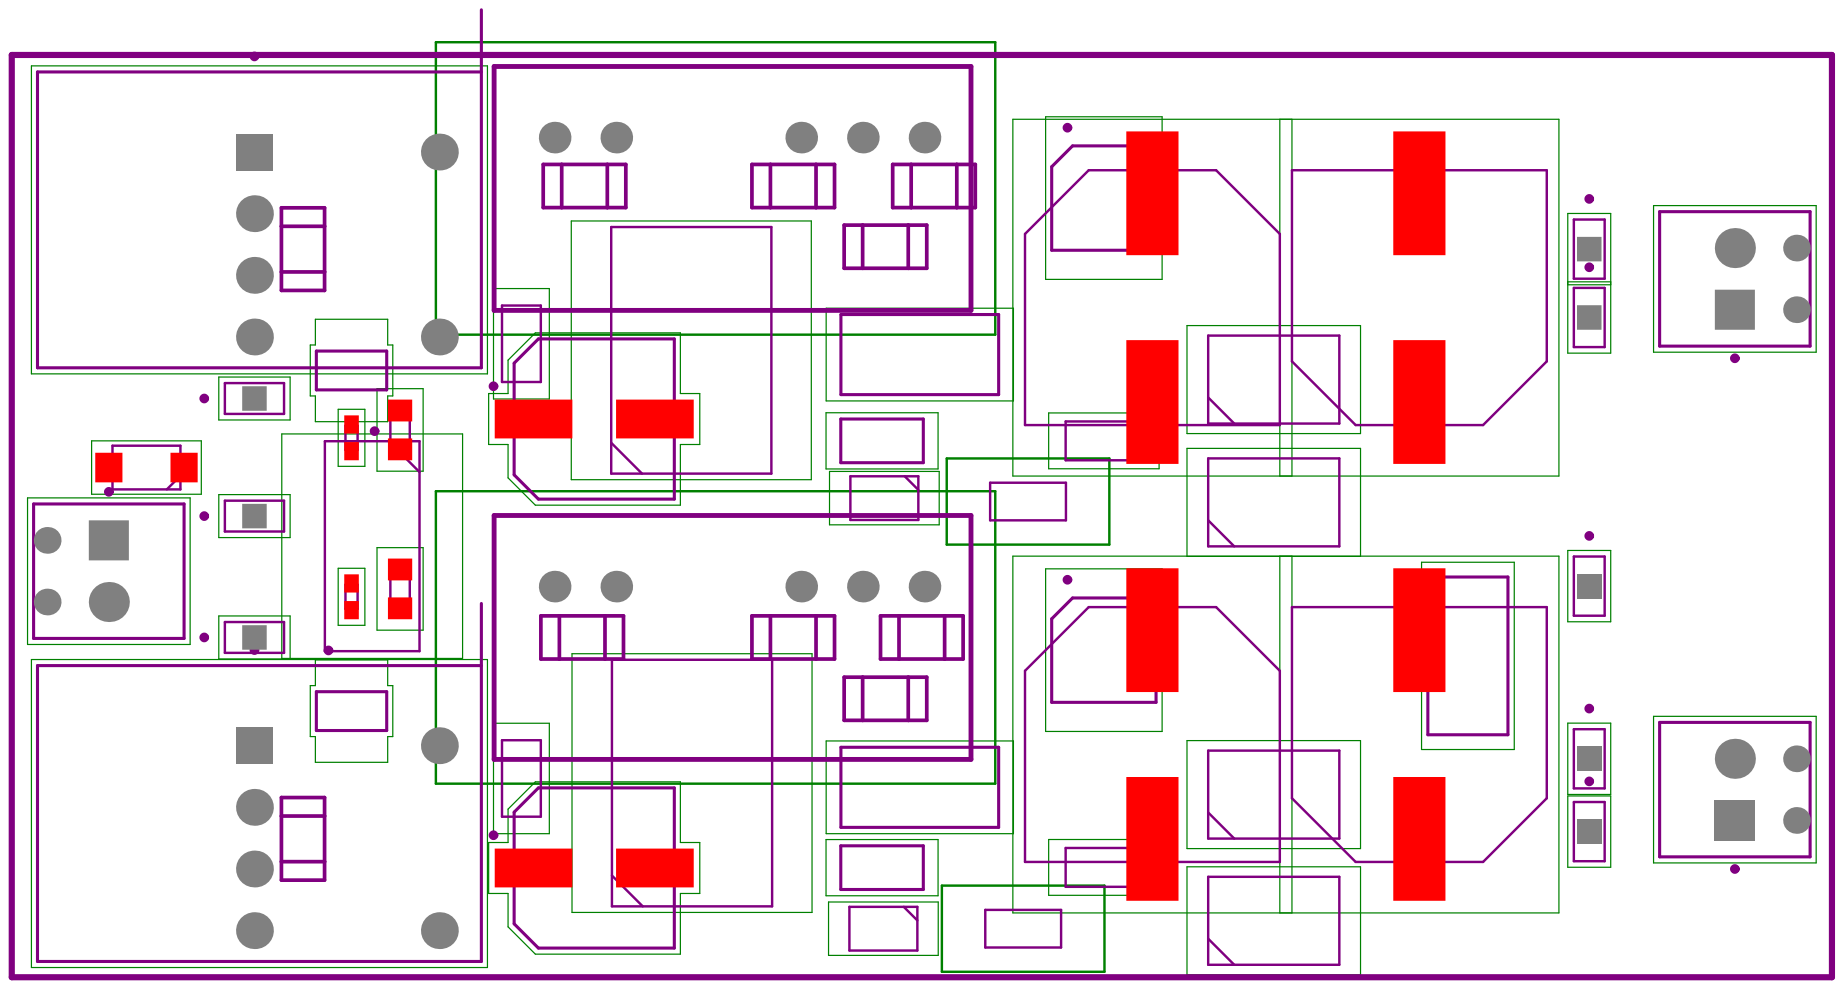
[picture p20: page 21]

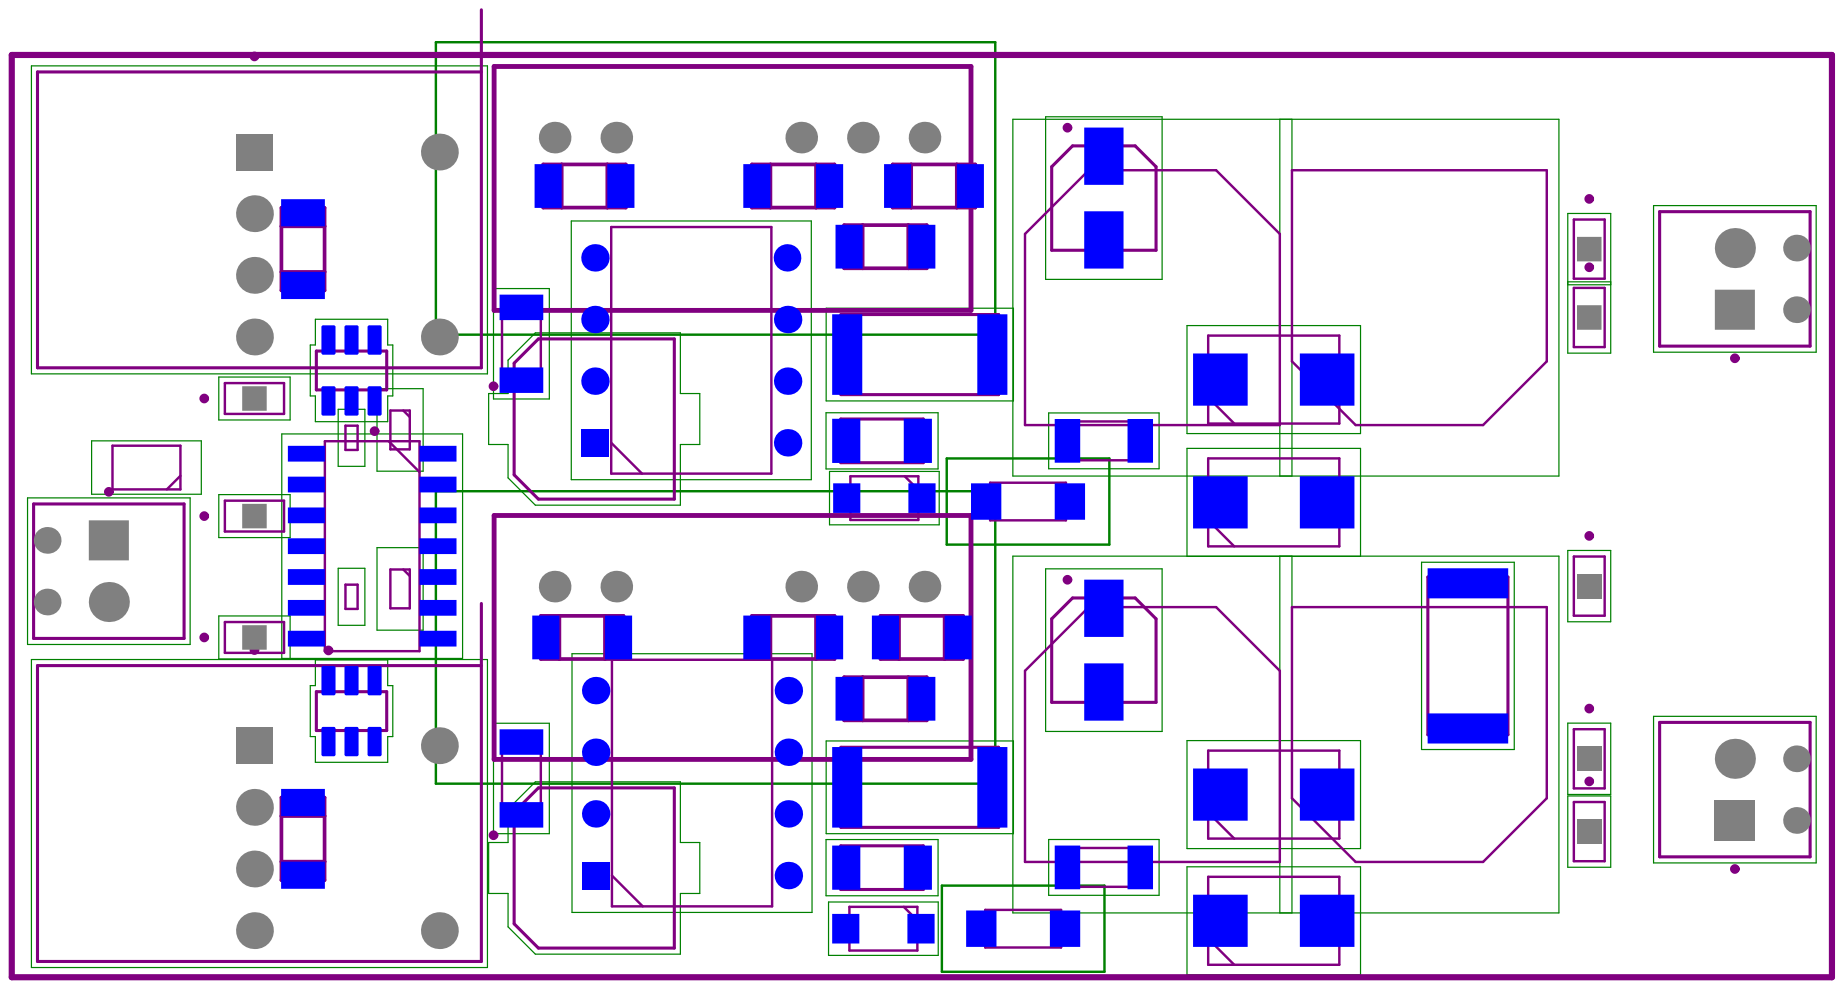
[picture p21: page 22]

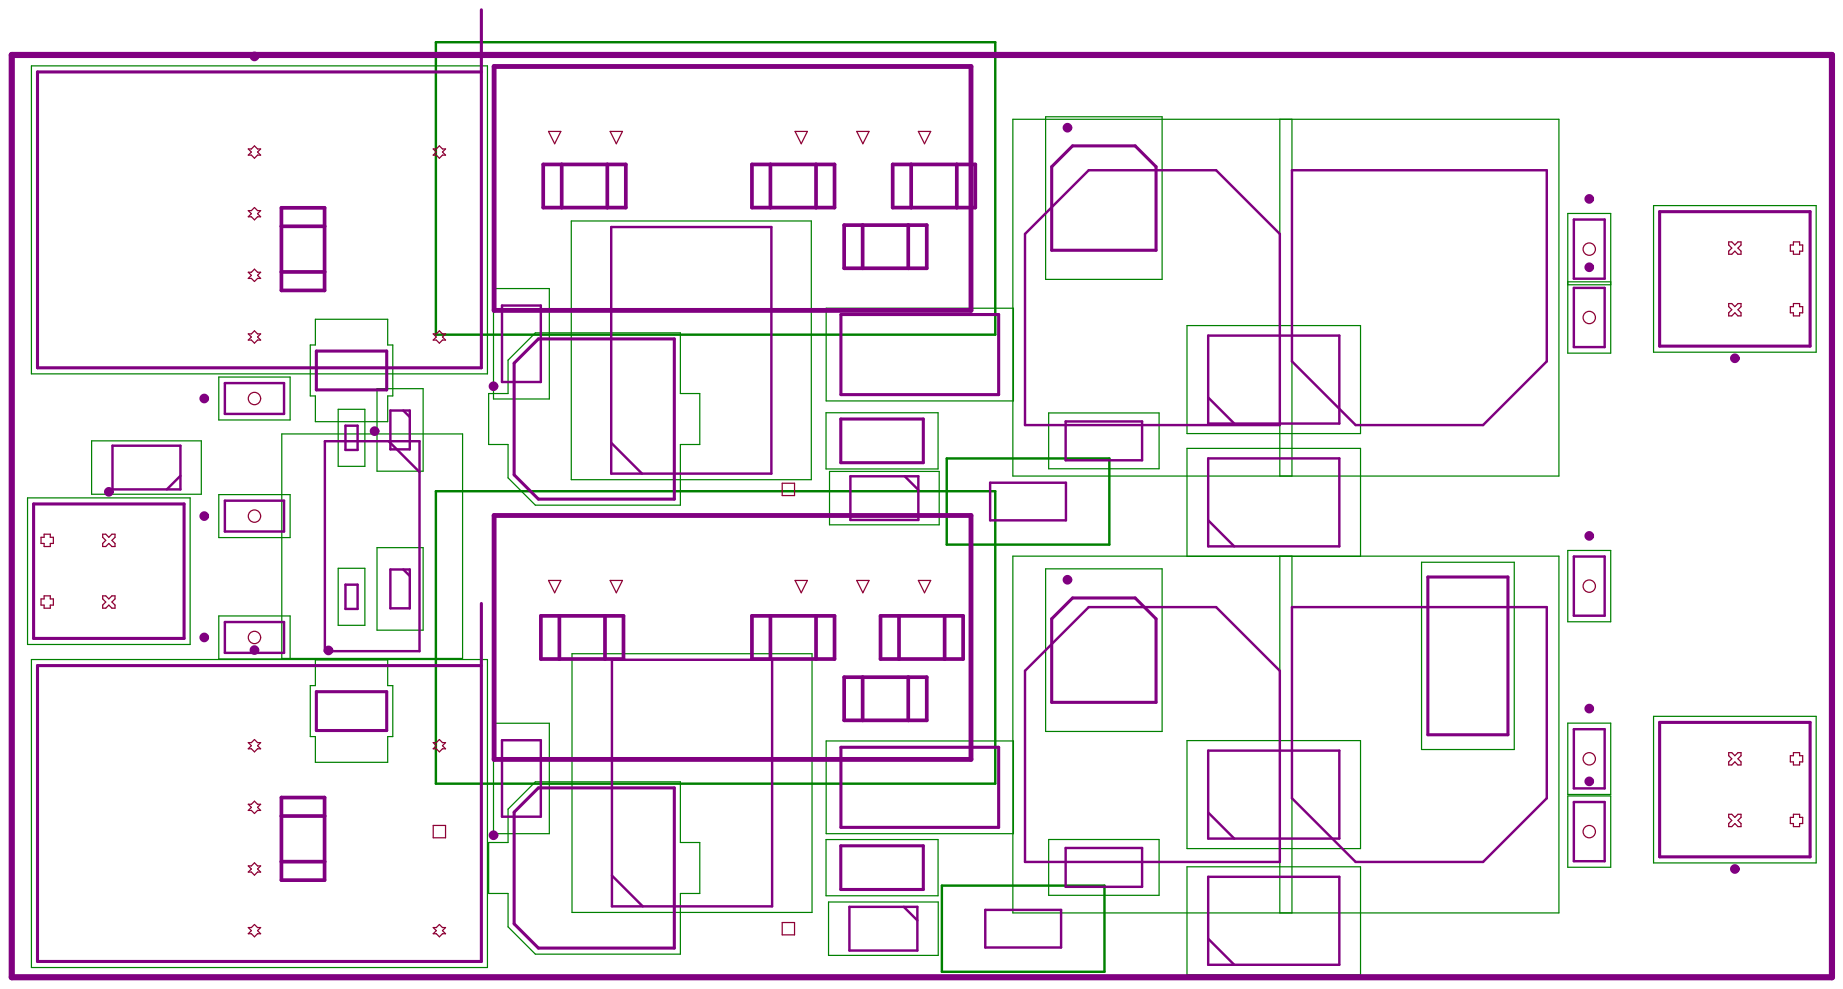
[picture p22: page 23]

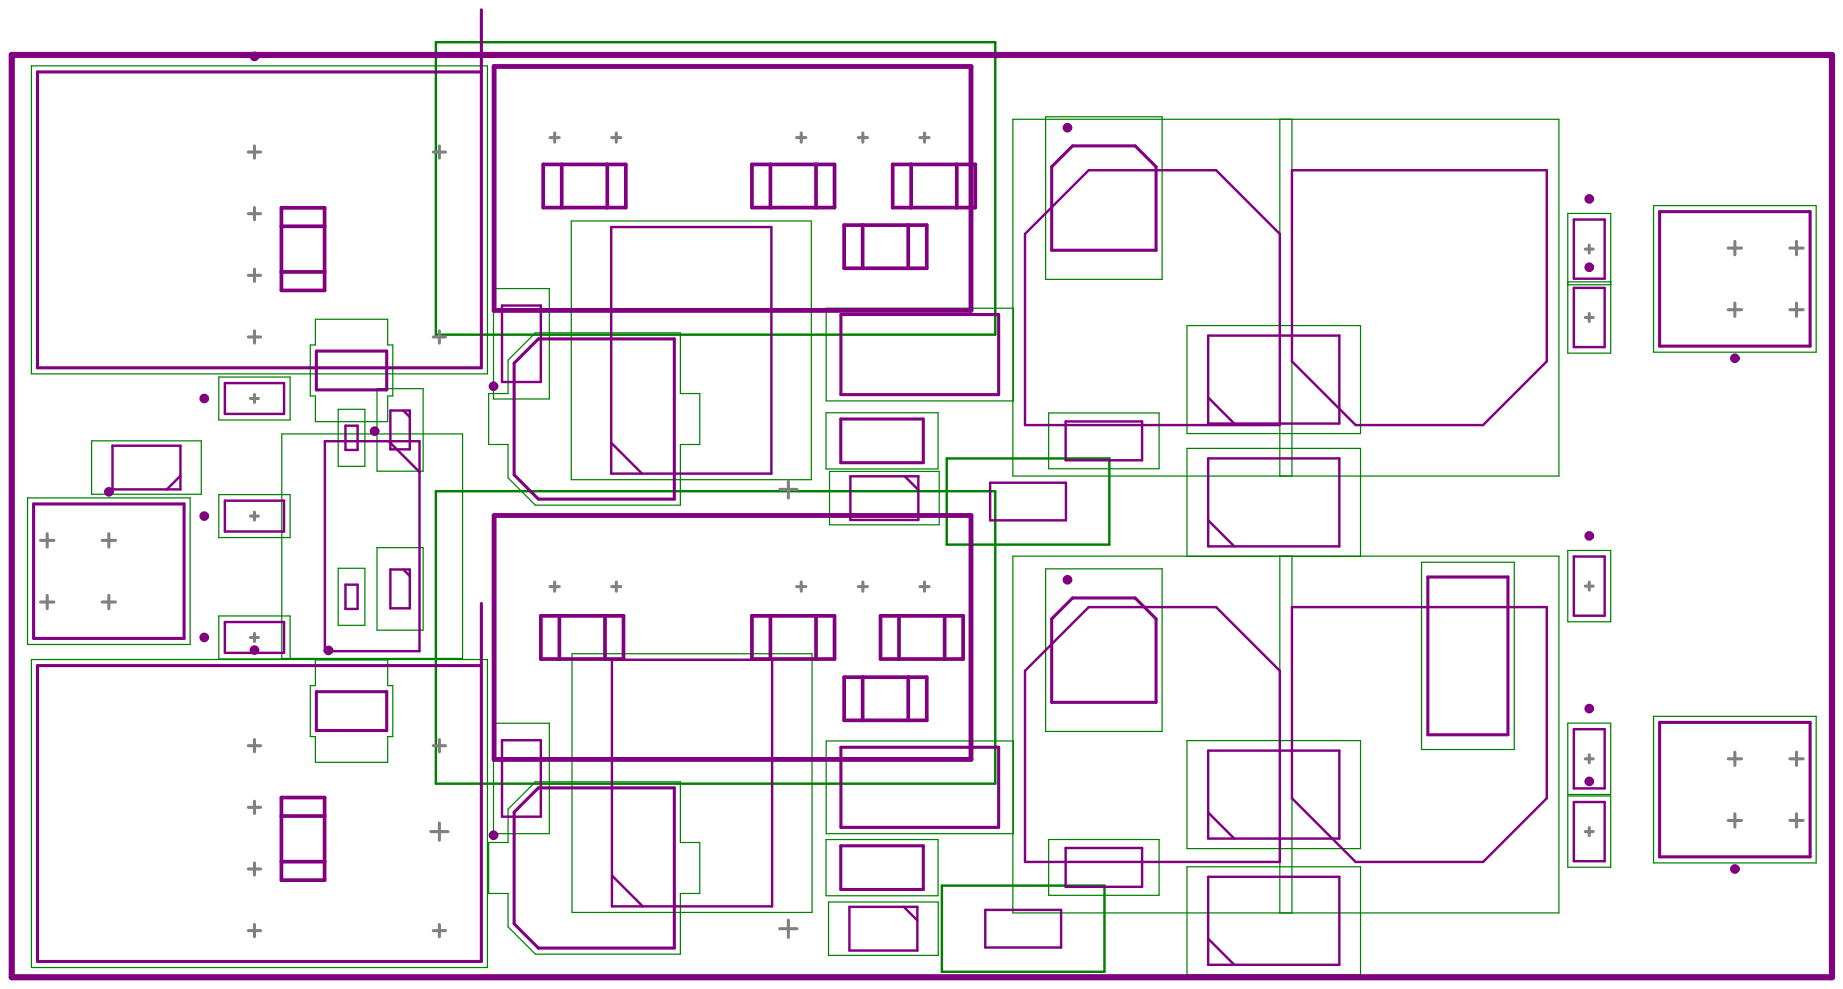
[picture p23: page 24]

DISCUSIÓN

Desafíos Técnicos

- | Footprints | Personalizados: | La | creación | del | footprint | para | el | capacitor
MCMHR63V104M4X7 (0.1uF) requirió realizar su pad size de acuerdo con los parámetros dados en la hoja de datos del componente.

Limitaciones y Mejoras Futuras

- Pruebas Experimentales: Pendiente medir comportamiento con osciloscopio de alta frecuencia, una vez impreso el PCB.

CONCLUSIONES

1. El diseño cumple con normativas IPC y requisitos técnicos para aplicaciones de energía renovable.
2. La integración de modelos 3D redujo errores en la fabricación.
3. El proyecto demuestra que es posible desarrollar drivers de potencia profesionales en entornos académicos.

Este reporte refleja el rigor de un proyecto en cual se han integrado desde detalles técnicos (normativas IPC, análisis de datasheets) hasta metodologías avanzadas de diseño.

BIBLIOGRAFÍA

- Mitzner, K. (2011). Complete PCB design using OrCad capture and layout. Elsevier.
- Jones, D. L. (2004). PCB design tutorial. June 29th, 3-25.
- Tähtinen, I. (2023). Design and simulation of a solid-state power switch for 48 V li-ion battery applications.
- Brooks, D. (2015). PCB Currents: How They Flow, How They React. Prentice Hall.
- PCB Capabilities - Custom PCB Prototype the Easy Way - PCBWay. (s. f.). https://www.pcbway.com/capabilities.html

- Marrakchi, D. (2024, 14 septiembre). Las 5 reglas de diseño de PCB más importantes que debes conocer. Altium. https://resources.altium.com/es/p/pcb-layout-guidelines
- Eurocircuits. (2025, 20 marzo). PCB Design Guidelines - Eurocircuits.

Eurocircuits. https://www.eurocircuits.com/technical-guidelines/pcb-design-

guidelines/

- Mohan, N., Undeland, T. M., & Robbins, W. P. (2003). Power electronics: converters, applications, and design. John wiley & sons.
- Texas Instruments. (2021). Gate Driver Design Basics.
- Altium Designer Documentation. (s. f.). Altium Documentation.

https://www.altium.com/documentation/altium-designer

- Bogatin, E. (2004). Signal integrity: simplified. Prentice Hall Professional.
- Montrose, M. I. (1996). Printed circuit board design techniques for EMC compliance (Vol. 1, p. 996). Piscataway, NJ: IEEE press.
- Traister, J. (2012). Design guidelines for surface mount technology. Elsevier.

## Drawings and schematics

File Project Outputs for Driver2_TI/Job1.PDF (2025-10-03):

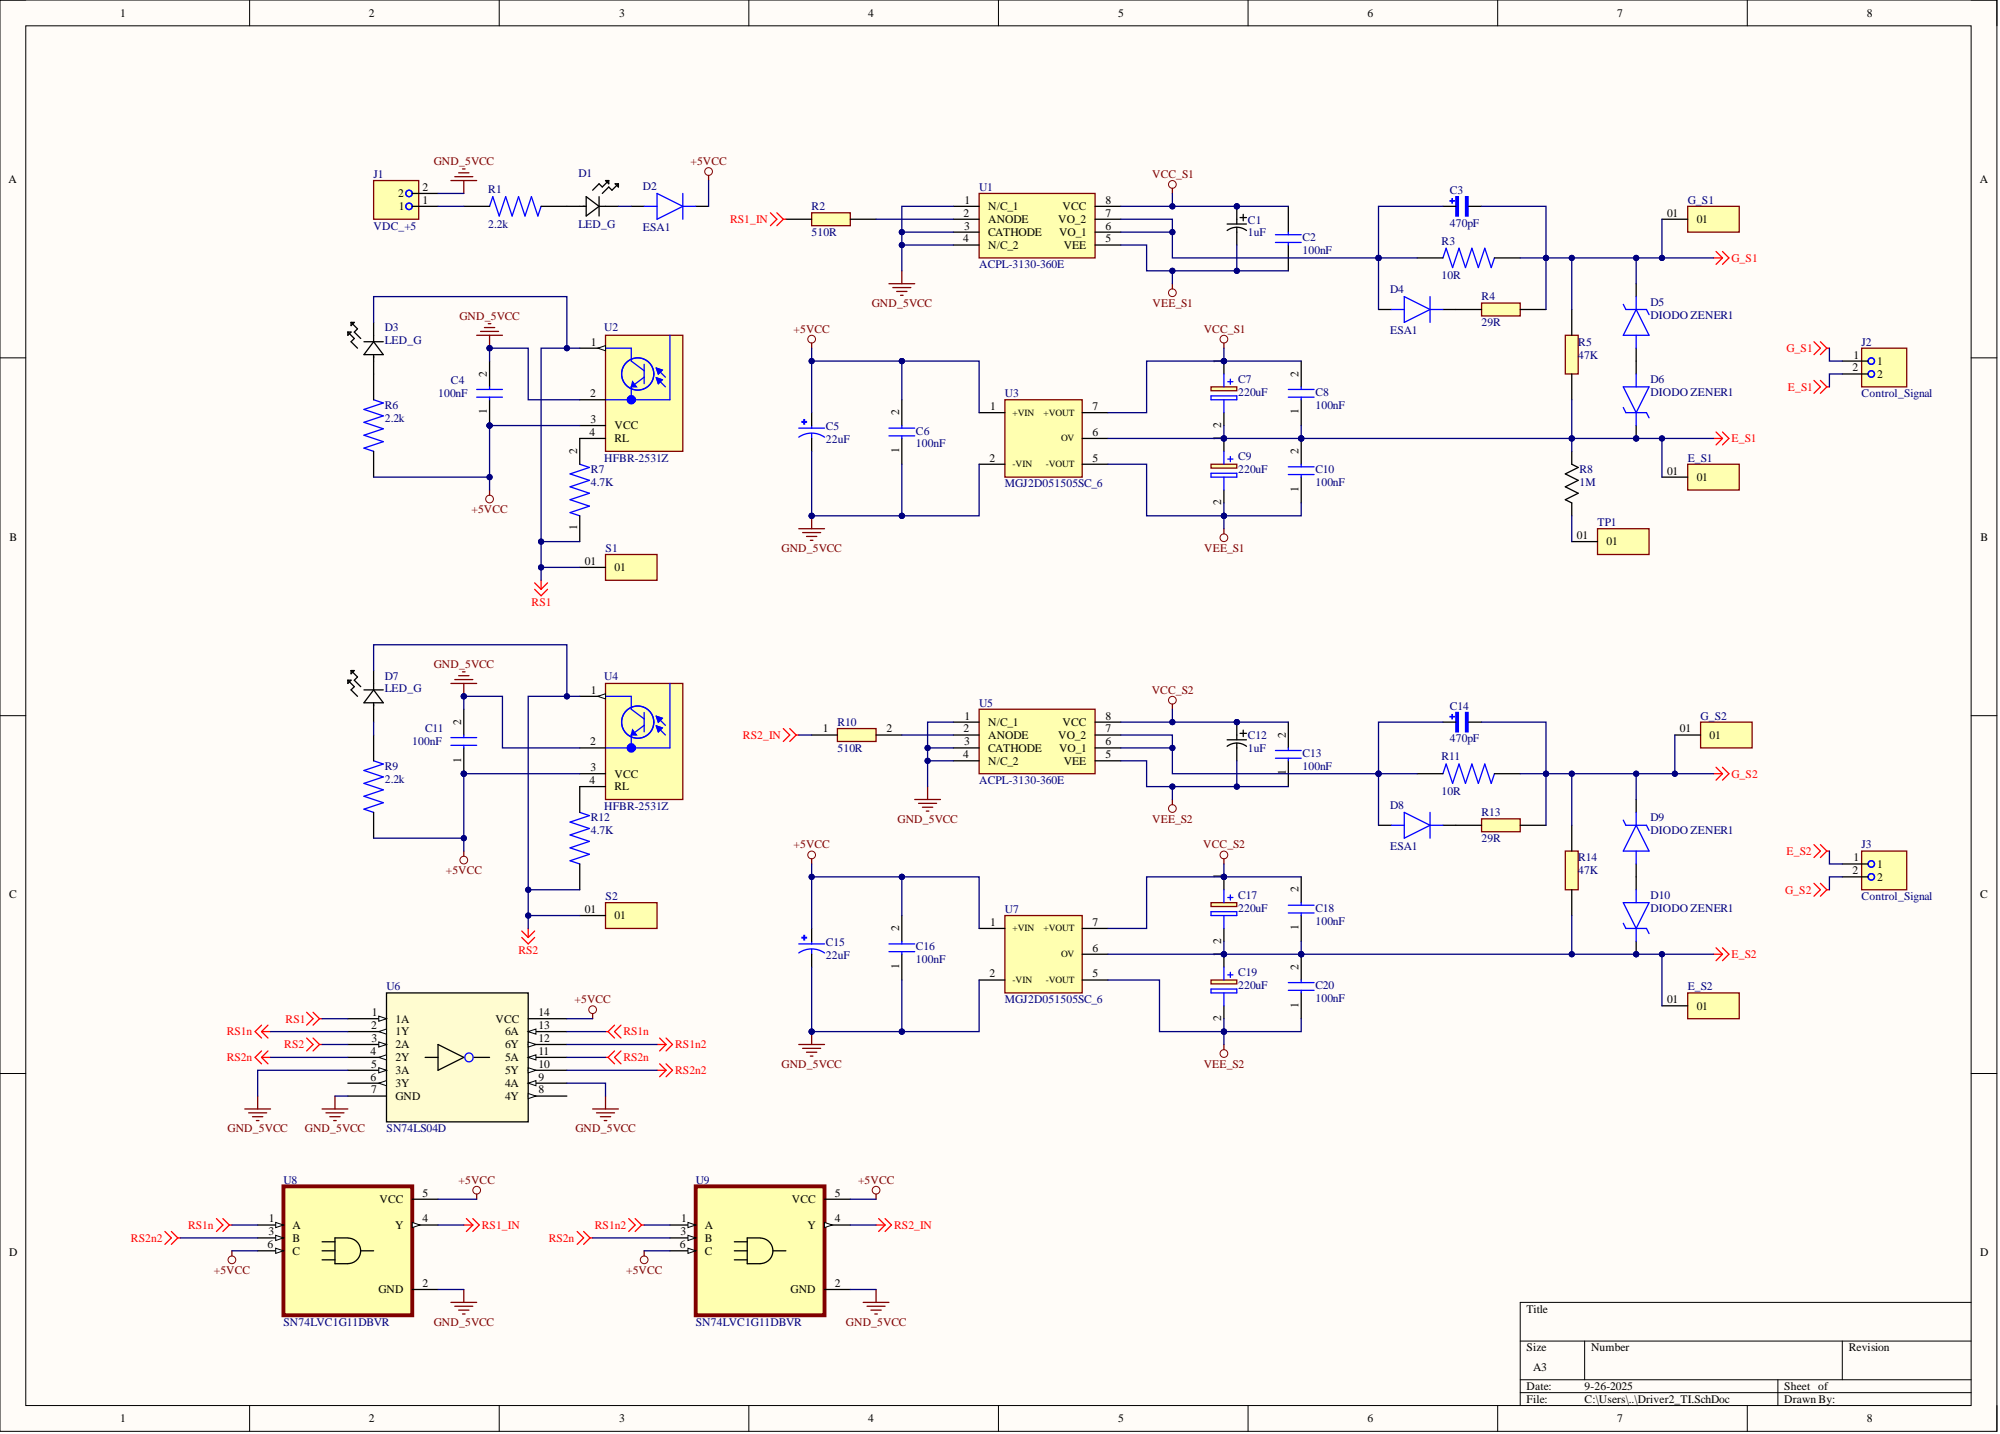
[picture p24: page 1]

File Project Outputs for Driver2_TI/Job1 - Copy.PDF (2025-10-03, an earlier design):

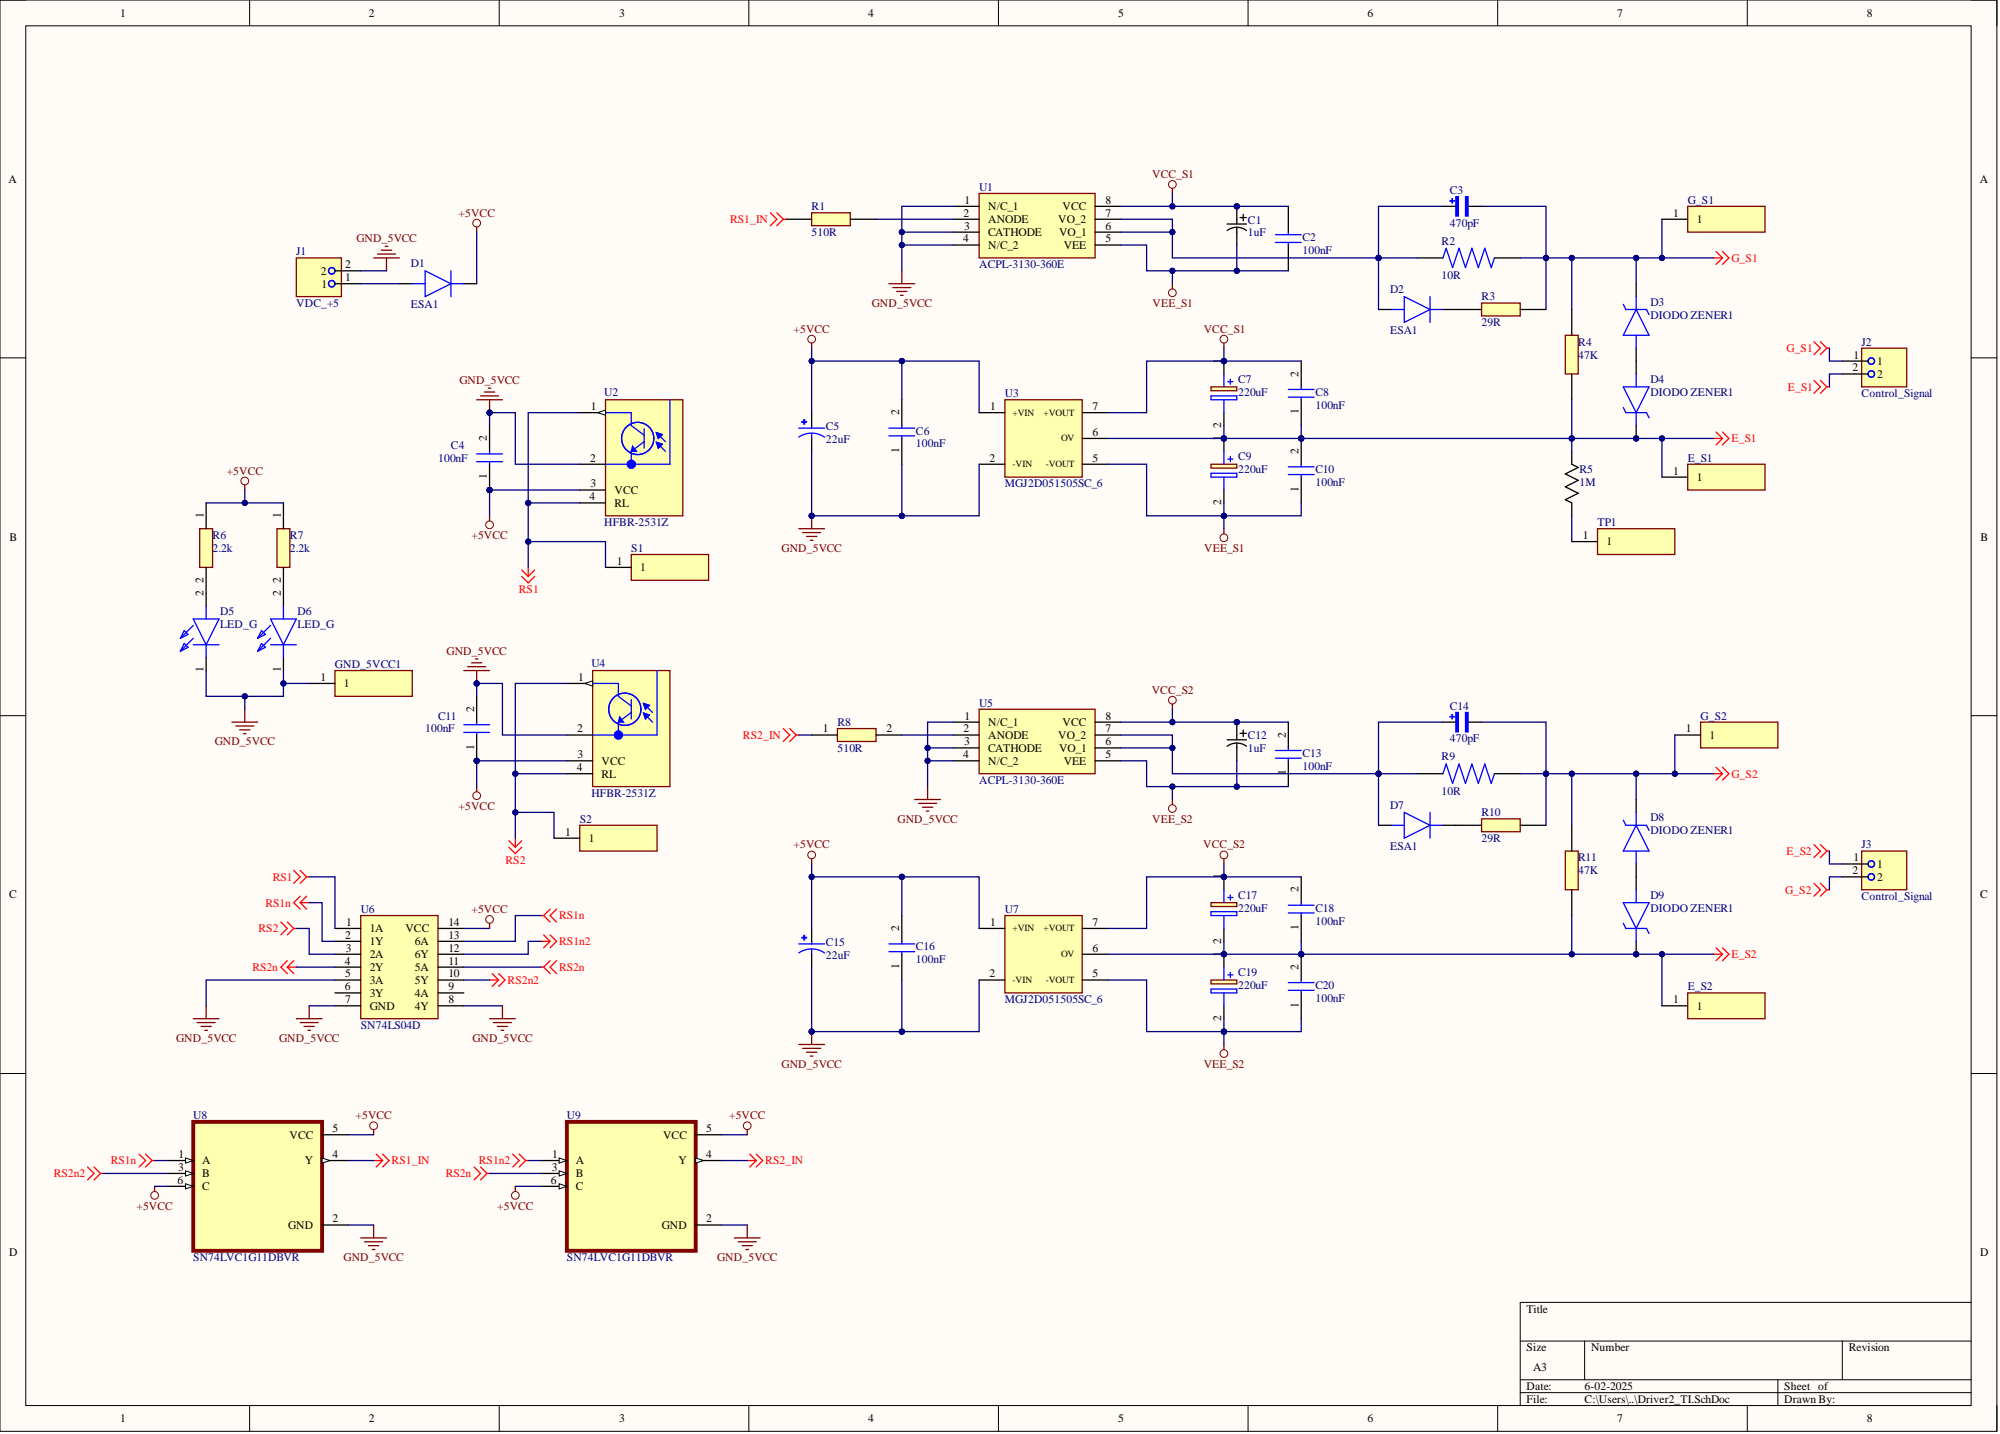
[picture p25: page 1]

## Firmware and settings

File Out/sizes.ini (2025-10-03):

[Page0.emf]
Pixel_PrintingWidth=2963
Pixel_PrintingHeight=1577
Mils_PrintingHeight=1577
Mils_PrintingWidth=2963
[Page1.emf]
Pixel_PrintingWidth=2963
Pixel_PrintingHeight=1577
Mils_PrintingHeight=1577
Mils_PrintingWidth=2963
[Page2.emf]
Pixel_PrintingWidth=2963
Pixel_PrintingHeight=1577
Mils_PrintingHeight=1577
Mils_PrintingWidth=2963
[Page3.emf]
Pixel_PrintingWidth=2963
Pixel_PrintingHeight=1577
Mils_PrintingHeight=1577
Mils_PrintingWidth=2963
[Page4.emf]
Pixel_PrintingWidth=2963
Pixel_PrintingHeight=1577
Mils_PrintingHeight=1577
Mils_PrintingWidth=2963
[Page5.emf]
Pixel_PrintingWidth=2963
Pixel_PrintingHeight=1577
Mils_PrintingHeight=1577
Mils_PrintingWidth=2963
[Page6.emf]
Pixel_PrintingWidth=2963
Pixel_PrintingHeight=1577
Mils_PrintingHeight=1577
Mils_PrintingWidth=2963
[Page7.emf]
Pixel_PrintingWidth=2963
Pixel_PrintingHeight=1577
Mils_PrintingHeight=1577
Mils_PrintingWidth=2963
[Page8.emf]
Pixel_PrintingWidth=2963
Pixel_PrintingHeight=1577
Mils_PrintingHeight=1577
Mils_PrintingWidth=2963
[Page9.emf]
Pixel_PrintingWidth=2963
Pixel_PrintingHeight=1577
Mils_PrintingHeight=1577
Mils_PrintingWidth=2963
[Page10.emf]
Pixel_PrintingWidth=2963
Pixel_PrintingHeight=1577
Mils_PrintingHeight=1577
Mils_PrintingWidth=2963
[Page11.emf]
Pixel_PrintingWidth=2963
Pixel_PrintingHeight=1577
Mils_PrintingHeight=1577
Mils_PrintingWidth=2963
[Page12.emf]
Pixel_PrintingWidth=2963
Pixel_PrintingHeight=1577
Mils_PrintingHeight=1577
Mils_PrintingWidth=2963
[Page13.emf]
Pixel_PrintingWidth=2963
Pixel_PrintingHeight=1577
Mils_PrintingHeight=1577
Mils_PrintingWidth=2963
[Page14.emf]
Pixel_PrintingWidth=2963
Pixel_PrintingHeight=1577
Mils_PrintingHeight=1577
Mils_PrintingWidth=2963

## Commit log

2025-10-03 CHECKPOINT: Subida inicial de los archivos de Altium (Diseno Funcional)
    [Driver2_TI.PcbLib, Driver2_TI.PrjPcb, Driver2_TI.SchDoc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]
2025-11-02 REPORTE SOBRE EL PROPOSITO DEL DRIVER
2025-11-02 Agrega los renders 3D del PCB en la carpeta Img/
